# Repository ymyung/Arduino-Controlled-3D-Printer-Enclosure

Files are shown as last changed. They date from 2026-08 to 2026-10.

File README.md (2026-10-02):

# Arduino-Controlled 3D Printer Enclosure

This portfolio project combines an Arduino-based temperature-control prototype with a later SolidWorks electronics-packaging extension. It documents analog temperature sensing, PWM fan actuation, prototype testing, electrical integration, parametric enclosure design, assembly modelling, and engineering drawings while keeping the original group work separate from the independent CAD work.

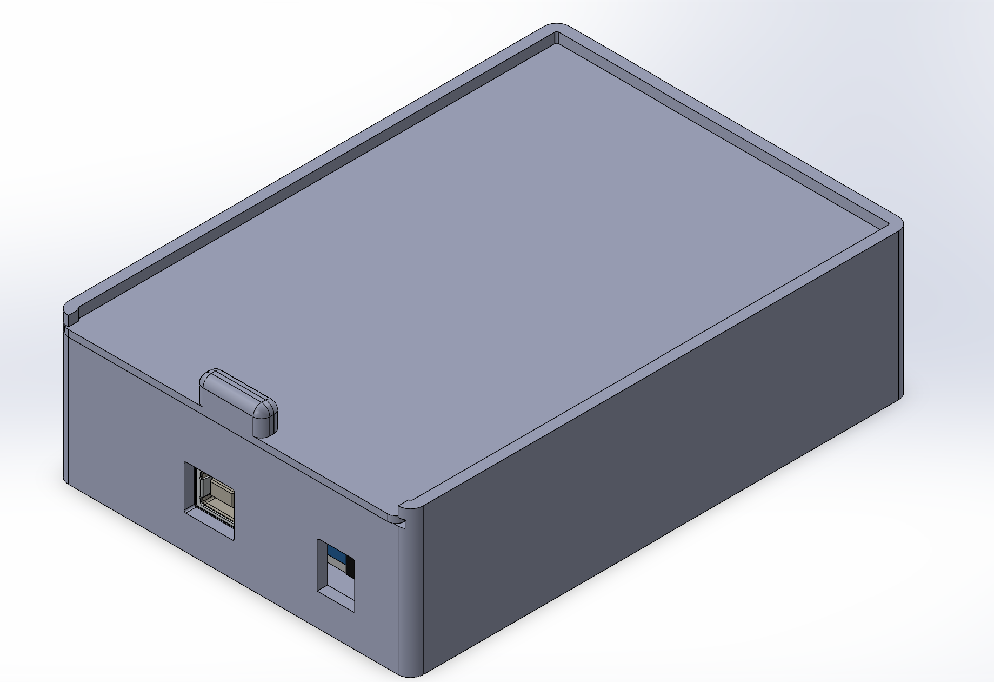
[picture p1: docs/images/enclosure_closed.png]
Closed SolidWorks assembly of the Arduino control enclosure


*Closed assembly showing the Arduino controller packaged within the electronics enclosure.*

## Project Overview

### Phase 1 - Thermal-Control Prototype

**Original group project | January-April 2025**

**My role: Electrical Lead**

The group project developed a temperature-regulation system for a 3D-printer enclosure. My work covered the Arduino control system, analog temperature-sensor integration, MOSFET-switched PWM fan control, live monitoring, electrical subsystem integration, system testing, troubleshooting, and wiring/system documentation.

The retained firmware and hardware documentation identify the sensor as an **LM35 analog temperature sensor**. It measures the main printer-enclosure temperature, and the cooling fans act on that main enclosure.

### Phase 2 - Mechanical Control Enclosure

**Independent mechanical design extension | 2026**

I later revisited the project independently to design a dedicated electronics/control enclosure in SolidWorks. This work was not part of the January-April 2025 group deliverable. It extends the project through mechanical packaging, Arduino placement, connector access, external cable routing, a guided sliding lid, assembly configurations, and a three-drawing documentation package.

## System Architecture

```mermaid
flowchart LR
    subgraph MAIN[Main printer enclosure]
        SENSOR[LM35 temperature sensor]
        FANS[DC cooling fans]
    end

    subgraph BOX[Electronics/control enclosure]
        MCU[Arduino Uno controller]
        LOGIC[Threshold and PWM logic]
        DRIVER[MOSFET fan driver]
    end

    SETPOINT[10 kOhm setpoint potentiometer] -->|A1| MCU
    SENSOR -->|External sensor connection / A0| MCU
    MCU --> LOGIC
    LOGIC -->|PWM D3| DRIVER
    DRIVER -->|External fan connection| FANS
    MCU -->|I2C| LCD[16 x 2 status display]
```

The mechanical control enclosure houses the Arduino/control hardware. The temperature sensor and cooling fans remain associated with the main printer enclosure, with their wiring routed through external enclosure connections.

## Mechanical Design

The independent SolidWorks work includes:

- a control-enclosure base with an approximately 120 mm x 85 mm x 35 mm overall envelope, approximately 2.5 mm walls, and R3 exterior corner treatment;
- Arduino mounting bosses/standoffs and packaging space for an Uno R3-style controller model;
- USB-B and power access plus routing for external sensor/fan wiring;
- rail/groove guide geometry for a removable sliding lid;
- an approximately 116 mm x 80.5 mm x 1.6 mm lid with a front pull feature and rear travel-limiting geometry;
- OPEN and CLOSED assembly configurations controlled by configuration-specific mates; and
- an exploded assembly representation for design communication.

The lid is screwless and is not documented as a snap-fit. The included Arduino model is used as a packaging reference; its original source and license are not established in the repository, so no authorship claim is made for that model.

See [Mechanical Design Notes](docs/mechanical-design.md) for the CAD structure, interfaces, and current validation boundaries.

## CAD Assembly

### Closed Configuration

Closed assembly

*Closed assembly showing the controller packaged within the electronics enclosure.*

### Open Configuration

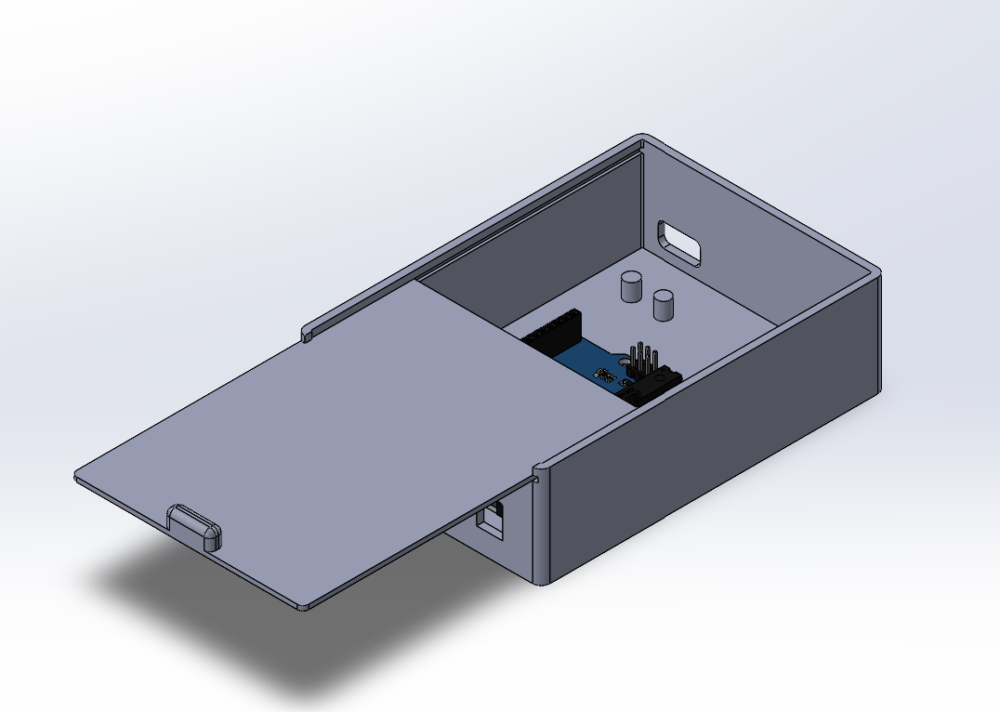
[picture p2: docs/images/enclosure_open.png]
Open assembly


*Open configuration showing the guided sliding-lid mechanism and internal component access.*

### Exploded Assembly

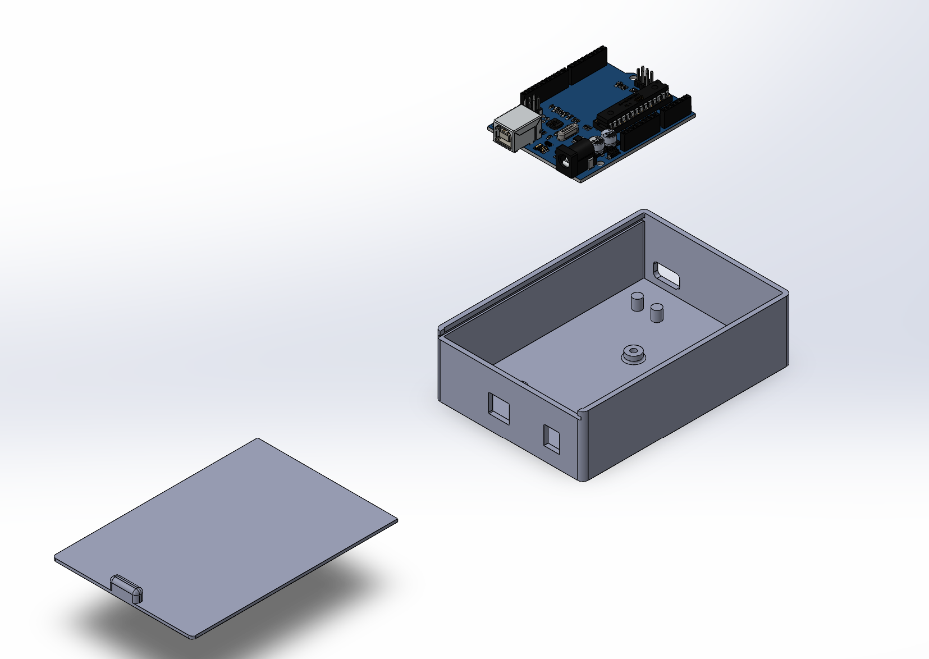
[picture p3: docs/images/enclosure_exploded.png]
Exploded assembly


*Exploded representation showing the relationship between the enclosure base, Arduino controller, and removable lid.*

## Component Design

### Control Enclosure Base

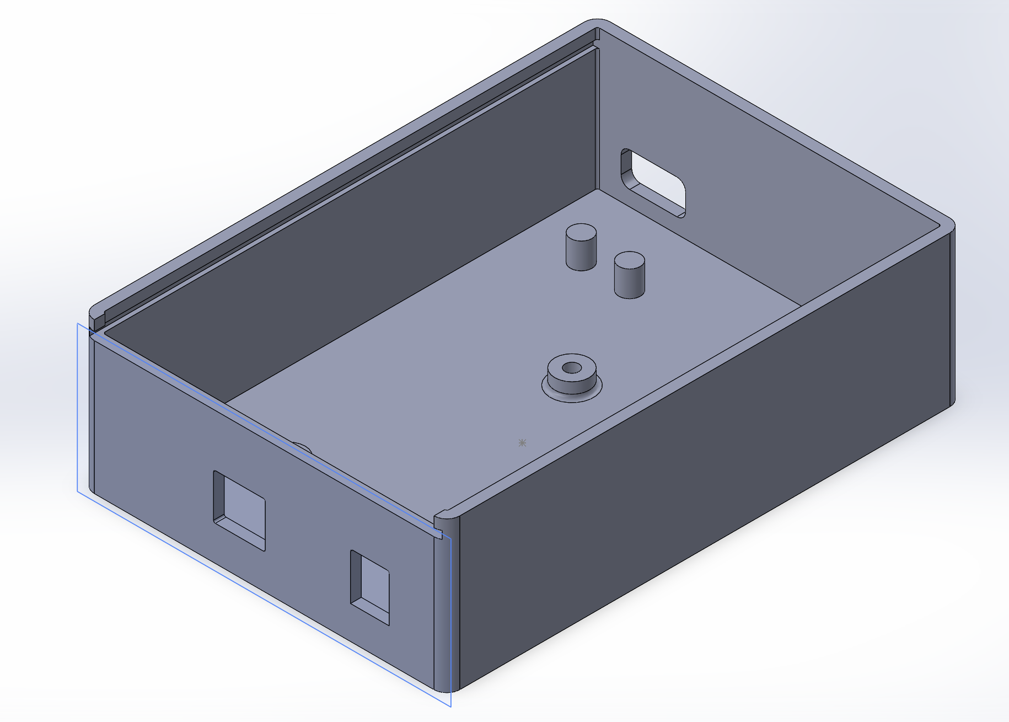
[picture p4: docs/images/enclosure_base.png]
Control enclosure base


*Base model incorporating controller mounting, connector access, external cable routing, and lid-guide geometry.*

### Sliding Lid

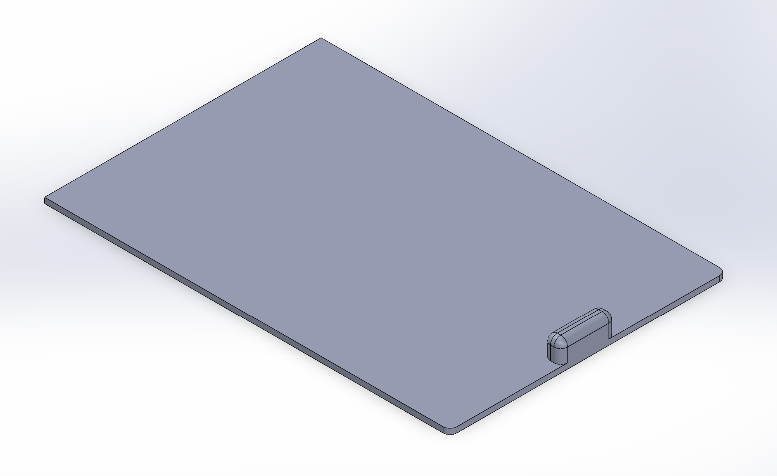
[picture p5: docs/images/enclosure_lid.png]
Sliding lid


*Removable lid designed around the enclosure rail/groove geometry, with a front pull feature.*

## Engineering Drawings

The native SolidWorks drawings are retained with the part and assembly files, with one-sheet PDF exports provided for browser-based review.

| Drawing | Description | PDF |
| --- | --- | --- |
| ACE-001 | Arduino Control Enclosure Base | [View Drawing](docs/drawings/ACE-001_Arduino_Control_Enclosure_Base.pdf) |
| ACE-002 | Arduino Control Enclosure Sliding Lid | [View Drawing](docs/drawings/ACE-002_Arduino_Control_Enclosure_Sliding_Lid.pdf) |
| ACE-003 | Arduino Control Enclosure Assembly | [View Drawing](docs/drawings/ACE-003_Arduino_Control_Enclosure_Assembly.pdf) |

ACE-001 includes dimensioned base views and section A-A; ACE-002 includes dimensioned lid and isometric views; ACE-003 includes closed, open, and exploded assembly views with a three-item BOM and item balloons. Exact source and output filenames are listed in [`docs/drawings/README.md`](docs/drawings/README.md). No claim is made for GD&T, production tolerances, material specifications, surface finish, or production readiness.

## Electrical & Control System

The retained Arduino firmware implements a threshold-based variable-speed controller:

- The LM35 signal on A0 and setpoint potentiometer on A1 are each averaged over 20 ADC samples.
- The potentiometer maps to a 25-40 °C threshold using floating-point range mapping.
- At or below the threshold, target fan PWM is zero.
- Above the threshold, the target command increases over the next 10 °C and is constrained to 80-255.
- A floating-point accumulator applies a 0.1 smoothing factor before the command is rounded for `analogWrite()`.
- PWM pin D3 drives the fan load through an n-channel MOSFET.
- A 16 x 2 I2C LCD and 9600-baud serial output report temperature, setpoint, and commanded fan percentage.

This is not PID control and it does not measure fan RPM. See the [firmware](firmware/fan_controller.ino) and [control-logic notes](docs/control_logic.md) for the implementation.

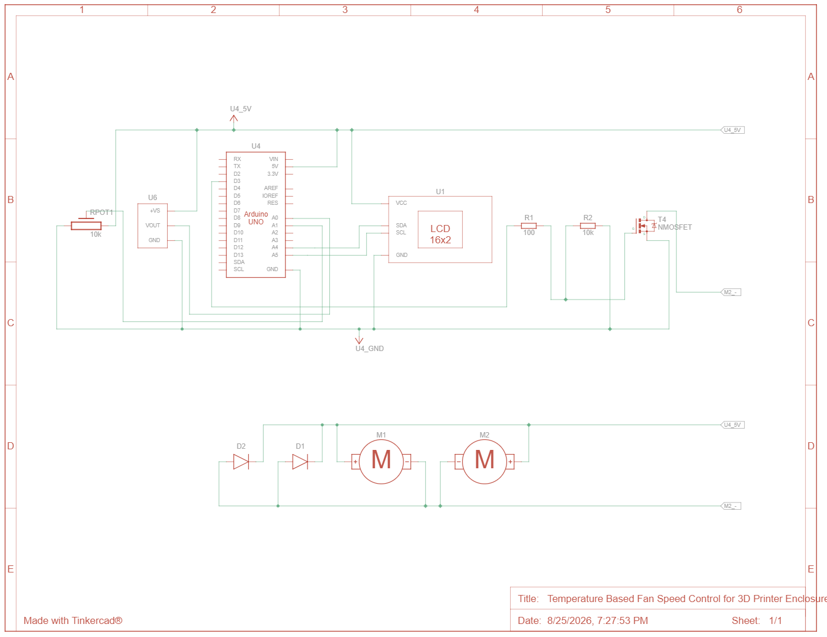
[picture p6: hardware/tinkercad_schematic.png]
Tinkercad schematic of the temperature-based fan-control circuit


*Retained circuit schematic. The TMP36 symbol is a visual stand-in for the LM35 documented in the physical prototype and firmware.*

## Testing and Retained Evidence

The original electrical prototype was operated while readings and system behaviour were monitored for integration, testing, and troubleshooting. Retained evidence includes the source code, Tinkercad schematic, component documentation, a [hosted prototype photo](https://github.com/user-attachments/assets/a48dc317-c163-46c9-83ad-6458d7b99006), and a [working-system demonstration](https://drive.google.com/file/d/1cJ_dpvMLTJp6Dsobzo3_qu-2Yc8-_ou2/view?usp=sharing).

This evidence is qualitative. The repository does not contain a retained calibration dataset, fan-RPM measurements, a controlled thermal-response dataset, or repeatability results; no numerical accuracy or closed-loop performance is claimed.

## Engineering Skills Demonstrated

**Mechanical:** SolidWorks, parametric part modelling, assembly modelling, mechanical packaging, engineering drawings, exploded assemblies, and component integration.

**Electrical / embedded:** Arduino programming, analog temperature sensing, ADC sampling, PWM control, MOSFET fan switching, LCD/serial monitoring, and hardware/software integration.

**Engineering practice:** electromechanical integration, prototype testing, troubleshooting, technical documentation, and iterative design.

## Repository Structure

```text
arduino-3d-printer-enclosure/
|-- README.md
|-- firmware/
|   `-- fan_controller.ino
|-- hardware/
|   |-- BOM.md
|   |-- README.md
|   |-- tinkercad_schematic.png
|   |-- tinkercad_component_list.png
|   `-- part files/
|       |-- Control_Enclosure_Base.SLDPRT
|       |-- Enclosure_lid.SLDPRT
|       |-- enclosure_assembly.SLDASM
|       |-- arduino uno.SLDPRT
|       `-- ACE-001/002/003 native SolidWorks drawings
|-- docs/
|   |-- control_logic.md
|   |-- design_decisions.md
|   |-- testing_and_limitations.md
|   |-- mechanical-design.md
|   |-- drawings/
|   |   `-- README.md
|   `-- images/
|       `-- five SolidWorks design views
`-- media/
    `-- README.md
```

Native CAD files remain in their original directory and retain their existing filenames to avoid disrupting assembly or drawing references.

## Design Status / Future Work

The repository contains the original controller firmware and qualitative prototype evidence, plus native CAD parts, an assembly, screenshots, three native drawings, and verified PDF exports for the independent mechanical extension. The control enclosure has not been documented here as physically fabricated or fit-validated.

Remaining engineering work includes:

- fabricating the control enclosure;
- verifying Arduino, connector, and cable fit on physical parts;
- checking sliding-lid operation and clearances after fabrication; and
- iterating the CAD and drawings from measured build results.

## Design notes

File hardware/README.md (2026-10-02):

# Hardware Documentation

This folder contains the retained electrical documentation and the native SolidWorks package for the 3D-printer enclosure controller.

- [`BOM.md`](BOM.md) - electrical bill of materials
- [`tinkercad_schematic.png`](tinkercad_schematic.png) - reconstructed Tinkercad circuit schematic
- [`tinkercad_component_list.png`](tinkercad_component_list.png) - component-list screenshot
- `part files/` - native enclosure parts, assembly, drawings, Arduino packaging model, and source screenshots

## Native CAD Safety

The files in `part files/` intentionally retain their current names and locations because SolidWorks assemblies and drawings can contain external references. Do not rename, move, or replace the native `.SLDPRT`, `.SLDASM`, or `.SLDDRW` files solely for repository organization.

The included `arduino uno.SLDPRT` is used as a packaging reference. Its original source and license are not documented here, so this project does not claim authorship of that model.

## Sensor Note

The physical prototype used an **LM35 analog temperature sensor**. Tinkercad did not provide an LM35 component, so the schematic uses a **TMP36 symbol only as a visual substitute**. The firmware is written for the LM35 transfer characteristic.

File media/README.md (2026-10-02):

# Demo Media

Qualitative evidence from the original electrical-control prototype is hosted externally:

- [Physical-prototype photograph](https://github.com/user-attachments/assets/a48dc317-c163-46c9-83ad-6458d7b99006)
- [Working-system demonstration](https://drive.google.com/file/d/1cJ_dpvMLTJp6Dsobzo3_qu-2Yc8-_ou2/view?usp=sharing)

These artifacts support the documented integration/testing history but do not provide a quantitative calibration, fan-RPM, response-time, or repeatability dataset. The later SolidWorks control enclosure is a separate 2026 design extension and is not shown as physically fabricated by this media.

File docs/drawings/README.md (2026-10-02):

# Engineering Drawing PDFs

This directory contains one-sheet PDF exports of the native SolidWorks engineering drawings retained in `hardware/part files/`. The native files remain the governing CAD documents and must not be renamed or moved because their references may depend on the existing paths.

The PDFs were opened with the Windows PDF renderer and visually checked for readable sheet output and the contents summarized below.

| Native drawing | PDF export | Verified sheet content |
| --- | --- | --- |
| `ACE-001_Arduino_Control_Enclosure_Base.SLDDRW` | [ACE-001 Base](ACE-001_Arduino_Control_Enclosure_Base.pdf) | Dimensioned base views, section A-A, and isometric view |
| `ACE-002_Sliding_Lid.SLDDRW` | [ACE-002 Sliding Lid](ACE-002_Arduino_Control_Enclosure_Sliding_Lid.pdf) | Dimensioned lid views and isometric view |
| `ACE-003_Arduino_Control_Enclosure_Assembly.SLDDRW` | [ACE-003 Assembly](ACE-003_Arduino_Control_Enclosure_Assembly.pdf) | Closed, open, and exploded assembly views; three-item BOM; item balloons |

When a native drawing changes, regenerate and revalidate its PDF without saving documentation-only changes back into the SolidWorks file.

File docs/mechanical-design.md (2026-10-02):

# Mechanical Design Notes

## Scope and Project History

The electronics/control enclosure is an independent 2026 extension of the original January-April 2025 group thermal-control project. It packages the Arduino/control hardware and provides the required external connections; it does not relocate the temperature sensor or cooling fans from the main printer enclosure.

The values below are the approximate dimensions recorded for this design. The native SolidWorks parts and drawings remain the governing design files.

## Enclosure Base

The control-enclosure base is approximately 120 mm x 85 mm x 35 mm overall, with approximately 2.5 mm walls and an R3 exterior corner treatment. Its functional features include:

- mounting bosses/standoffs for an Arduino Uno R3-style controller;
- access for the board's USB-B and power connections;
- an opening for external sensor/fan cable routing; and
- rail/groove geometry that guides the removable lid.

The base is represented by `hardware/part files/Control_Enclosure_Base.SLDPRT` and drawing ACE-001.

## Sliding Lid

The lid is approximately 116 mm x 80.5 mm x 1.6 mm. It slides within the enclosure guide geometry and includes a front pull/finger feature. Rear geometry limits lid travel/closure. The design does not use screws, and no snap-fit behaviour is claimed.

The lid is represented by `hardware/part files/Enclosure_lid.SLDPRT` and drawing ACE-002.

## Assembly Model

The assembly combines the enclosure base, sliding lid, and an Arduino Uno R3-style packaging model. It includes OPEN and CLOSED configurations with configuration-specific mates controlling lid position, plus an exploded representation.

The Arduino model supports placement and access studies. Its original source and license are not documented in this repository, so the project does not claim authorship of that model.

The assembly is represented by `hardware/part files/enclosure_assembly.SLDASM` and drawing ACE-003.

## Electromechanical Interfaces

The packaging work addresses the interfaces visible in the retained CAD:

- controller support and placement inside the base;
- external access to USB-B and power connections;
- routing for wiring to the printer-enclosure temperature sensor and fan load; and
- access to the electronics through the removable lid.

The temperature sensor and cooling fans remain part of the main printer-enclosure system rather than components inside this control box.

## Native CAD and Drawing Package

The native directory intentionally retains the original filenames because SolidWorks parts, assemblies, and drawings can depend on path and filename references. The directory contains:

| File | Purpose |
| --- | --- |
| `Control_Enclosure_Base.SLDPRT` | Enclosure base part |
| `Enclosure_lid.SLDPRT` | Sliding-lid part |
| `enclosure_assembly.SLDASM` | Control-enclosure assembly |
| `arduino uno.SLDPRT` | Arduino packaging model; authorship/source not established here |
| `ACE-001_Arduino_Control_Enclosure_Base.SLDDRW` | Base drawing |
| `ACE-002_Sliding_Lid.SLDDRW` | Lid drawing |
| `ACE-003_Arduino_Control_Enclosure_Assembly.SLDDRW` | Assembly drawing |

## Current Validation Boundary

The repository does not contain evidence that the mechanical enclosure was fabricated or physically fit-checked. It also does not establish production tolerances, material specifications, surface finish, tolerance-stack analysis, interference validation, DFM validation, FEA, CFD, thermal simulation, or airflow improvement. Those items are outside the documented scope until supported by future build and validation work.

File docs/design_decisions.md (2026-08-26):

# Design Decisions

This document records the main electrical and firmware choices visible in the retained project artifacts.

## 1. LM35 temperature sensing

The physical prototype used an **LM35** analog temperature sensor. The firmware assumes the LM35 relationship of approximately 10 mV/°C and converts the measured ADC voltage using:

```cpp
float tempVoltage = tempAvg * (5.0 / 1023.0);
float temperatureC = tempVoltage * 100.0;
```

The Tinkercad schematic uses a TMP36 symbol because an LM35 component was not available in that environment. The TMP36 is a schematic stand-in only and should not be used to interpret the firmware conversion.

## 2. User-adjustable temperature threshold

A **10 kΩ potentiometer** provides an analog input that is mapped to a 25–40 °C setpoint. This makes the cooling threshold adjustable without recompiling the firmware.

## 3. MOSFET interface for the fans

The Arduino generates the fan command as a PWM signal on pin D3. An **n-channel MOSFET** is used as the switching element between the Arduino control signal and the fan load.

The retained schematic also includes a 100 Ω resistor in the MOSFET gate path and a 10 kΩ resistor at the gate control node.

## 4. Analog input averaging

Both the temperature and potentiometer signals are averaged over **20 ADC readings**. The intent is to reduce short-term fluctuations before the values are used by the controller.

## 5. Threshold-based variable-speed control

The system does not use PID control. The logic is:

- at or below the selected threshold: target PWM = 0;
- above the threshold: target PWM increases with measured temperature;
- active target PWM is constrained to 80–255.

This gives the system variable fan command above the threshold while avoiding very low active PWM commands.

## 6. Smoothed PWM command

Rather than switching immediately to each newly calculated target, the firmware updates the output using:

```text
smoothedPWM = smoothedPWM + 0.1 × (targetPWM - smoothedPWM)
```

This makes commanded fan-speed changes more gradual.

## 7. Two forms of operating feedback

The project uses both:

- a **16×2 I²C LCD** for local feedback; and
- **9600-baud serial output** for diagnostic monitoring during development and testing.

The LCD presents measured temperature, selected threshold, and commanded fan percentage.

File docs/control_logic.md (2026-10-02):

# Control Logic

## Overview

The enclosure uses a threshold-based variable-speed cooling strategy.

The controller has two primary inputs:

1. Enclosure temperature measured using an LM35 sensor
2. Desired temperature selected using a potentiometer

The primary output is a PWM command sent from the Arduino to the MOSFET controlling the two fans.

The controller does not measure actual fan RPM.

## Control Sequence

Each control cycle follows this sequence:

```text
Read LM35
    |
    v
Average ADC samples
    |
    v
Convert ADC value to voltage
    |
    v
Convert voltage to temperature
    |
    +----------------------+
                           |
Read potentiometer         |
    |                      |
    v                      |
Average ADC samples        |
    |                      |
    v                      |
Map reading to 25-40 C ----+
                           |
                           v
               Compare temperature
                   with setpoint
                           |
             +-------------+-------------+
             |                           |
      Temp <= Setpoint            Temp > Setpoint
             |                           |
             v                           v
       Target PWM = 0          Calculate PWM 80-255
             |                           |
             +-------------+-------------+
                           |
                           v
                     Smooth output
                           |
                           v
                    MOSFET PWM signal
                           |
                           v
                       Two fans
```

## Input Averaging

Both analog inputs are sampled 20 times.

The samples are averaged before being used by the controller.

This reduces small ADC fluctuations without requiring additional filtering hardware.

The firmware uses:

```cpp
const int NUM_SAMPLES = 20;
```

with approximately 2 ms between individual samples.

## LM35 Temperature Conversion

The Arduino Uno ADC produces values from:

```text
0 to 1023
```

using an approximately 5 V reference.

Voltage is calculated as:

```text
voltage = ADC × (5.0 / 1023)
```

The physical prototype used an LM35 sensor.

The LM35 produces approximately:

```text
10 mV / °C
```

Therefore:

```text
temperature (°C) = voltage / 0.010
```

The Tinkercad schematic uses a TMP36 symbol only because the original simulation environment did not provide the LM35 component.

The firmware uses the LM35 conversion relationship.

## Setpoint Calculation

The potentiometer is connected to a second analog input.

Its averaged ADC reading is mapped to:

```text
25 °C to 40 °C
```

The controller uses floating-point mapping rather than Arduino's standard integer `map()` function so fractional averaged ADC values and temperature values can be preserved.

## Cooling Threshold

When:

```text
measured temperature <= desired temperature
```

the target fan PWM is:

```text
0
```

When:

```text
measured temperature > desired temperature
```

active cooling begins.

## Variable Fan Command

Once active cooling is required, the target PWM command begins at:

```text
80 / 255
```

and increases as measured temperature rises.

The controller reaches maximum commanded PWM when the measured temperature is approximately:

```text
10 °C above the selected setpoint
```

Therefore the operating relationship is approximately:

```text
T <= Tset
PWM = 0
```

```text
Tset < T < Tset + 10 °C
PWM = proportional value between 80 and 255
```

```text
T >= Tset + 10 °C
PWM = 255
```

The value 80 was used as the minimum active PWM command because very small PWM duty cycles may not reliably start a DC fan.

No fan-start threshold was experimentally characterized and retained, so this value should not be interpreted as a measured minimum operating requirement.

## PWM Smoothing

The controller applies exponential smoothing to PWM changes:

```text
smoothedPWM =
smoothedPWM
+ (targetPWM - smoothedPWM) × 0.10
```

A floating-point accumulator is used to prevent fractional updates from being lost through integer truncation.

When cooling first becomes active, the **target** command is at least 80/255. Because the actual output is smoothed toward that target, the first PWM values sent by `analogWrite()` can be below 80.

When cooling is no longer required, the command decreases toward zero.

When the floating-point accumulator falls below 1.0 with a zero target, the firmware sets it to zero.

The purpose of smoothing is to reduce abrupt changes in commanded fan output.

## MOSFET Output Stage

Arduino PWM pin 3 provides the control signal to the N-channel MOSFET circuit.

The Arduino does not directly supply the fan operating current.

Instead:

```text
Arduino PWM
    |
    v
MOSFET gate
    |
    v
MOSFET switches fan current
    |
    v
Two DC fans
```

## Fan Percentage

The displayed fan percentage is calculated from the PWM command:

```text
fan percentage =
PWM / 255 × 100
```

For example:

```text
PWM = 128
```

corresponds to approximately:

```text
50% commanded PWM
```

This does not mean the fan is rotating at 50% of its maximum RPM.

Actual fan speed was not measured.

## Controller Classification

The system should be described as:

> Threshold-based variable-speed fan control with PWM output smoothing.

It should not be described as:

- PID control
- Closed-loop fan-speed control
- Closed-loop RPM control

The temperature measurement influences fan command, but there is no feedback measurement of actual fan speed.

## Update Rate

The main control logic runs approximately every:

```text
500 ms
```

Additional time is required to acquire the averaged analog samples.

This update rate was sufficient for the relatively slow thermal behavior of the enclosure prototype.

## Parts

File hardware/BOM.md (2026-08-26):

# Bill of Materials

The following list is based on the retained Tinkercad component list and the known physical build.

| Component | Quantity | Notes |
|---|---:|---|
| Arduino Uno R3 | 1 | Main controller |
| LM35 temperature sensor | 1 | Used in the physical prototype |
| 10 kΩ potentiometer | 1 | User-adjustable temperature setpoint |
| 16×2 I²C LCD (PCF8574-based, address 0x27 in firmware) | 1 | Displays measured temperature, setpoint, and commanded fan output |
| DC fan / DC motor | 2 | Cooling loads controlled together |
| n-channel MOSFET | 1 | Switches the fan load from the Arduino PWM signal |
| 100 Ω resistor | 1 | Shown in the MOSFET gate path in the schematic |
| 10 kΩ resistor | 1 | Shown as the MOSFET gate pull-down in the schematic |
| Diode | 2 | Included with the two motor branches in the retained schematic |
| Small breadboard | 1 | Prototype wiring |

## Tinkercad sensor substitution

The physical prototype used an **LM35** temperature sensor. Tinkercad did not provide an LM35 component, so the retained Tinkercad schematic uses a **TMP36 symbol as a visual stand-in**. The firmware is written for the LM35 transfer characteristic, not the TMP36 transfer characteristic.

See [`tinkercad_component_list.png`](tinkercad_component_list.png) for the original component-list screenshot.

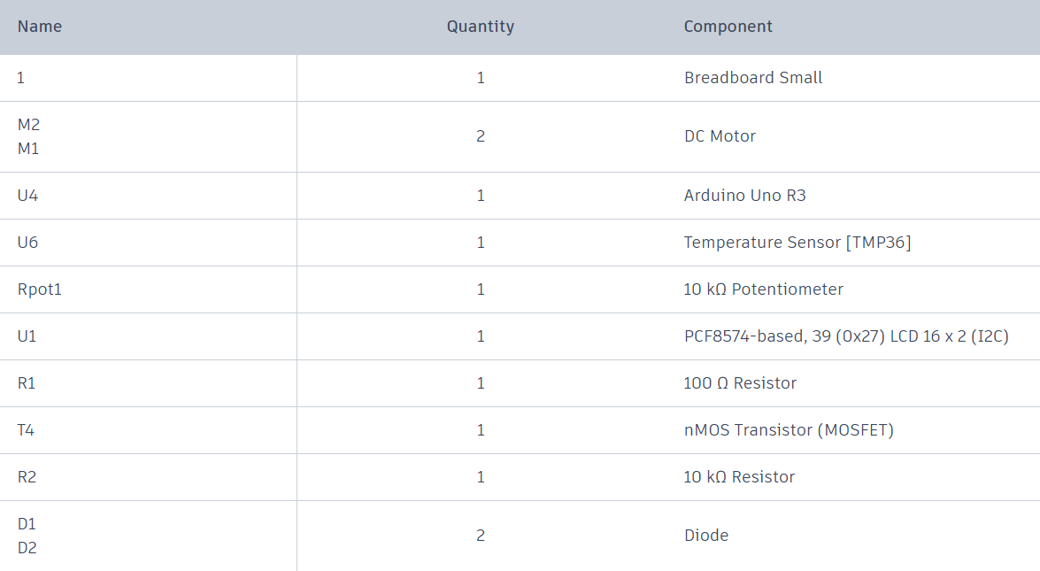
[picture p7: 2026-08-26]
hardware/tinkercad_component_list.png

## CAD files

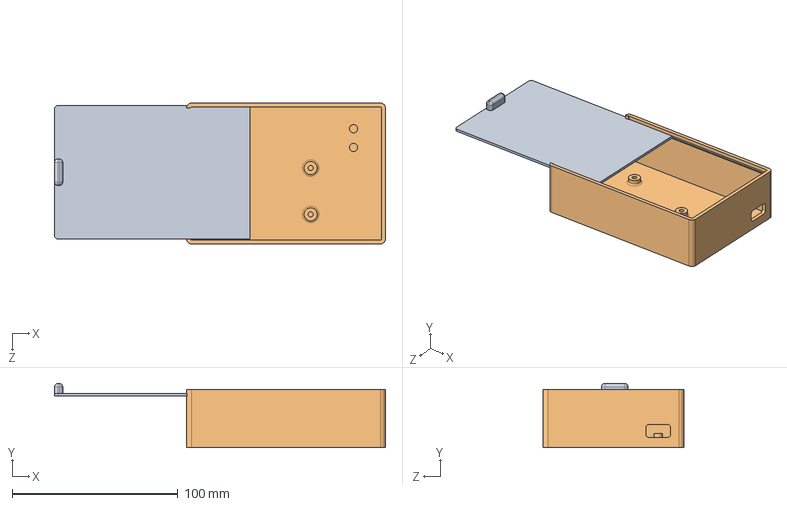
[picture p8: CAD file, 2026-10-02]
hardware/part files/enclosure_assembly.SLDASM
199.6 x 38.6 x 85.0 mm
Control_Enclosure_Base
Enclosure_lid

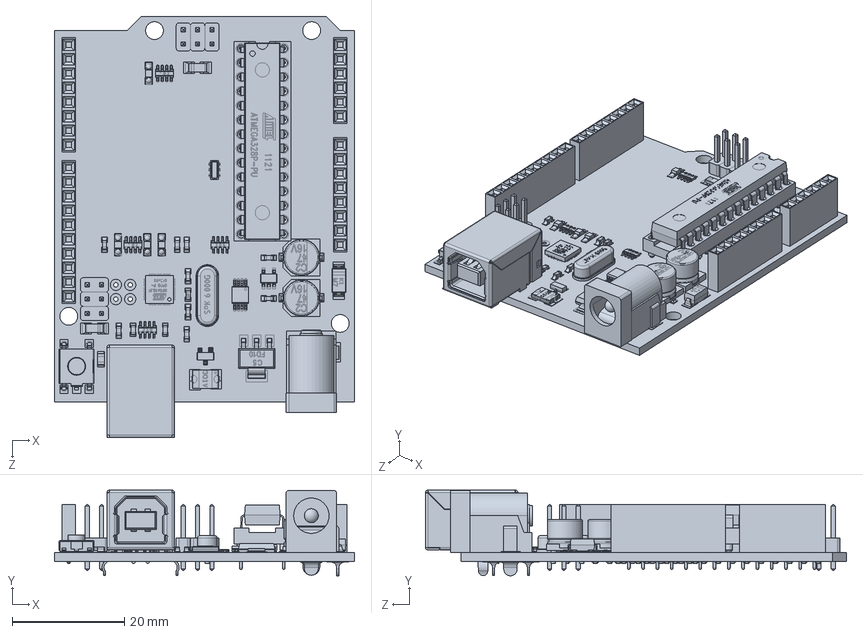
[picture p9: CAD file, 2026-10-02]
hardware/part files/arduino uno.SLDPRT
53.3 x 15.2 x 74.9 mm

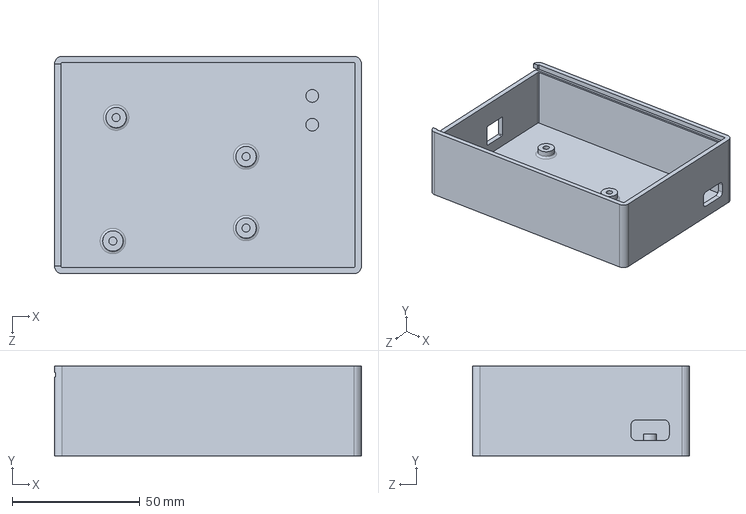
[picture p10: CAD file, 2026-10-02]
hardware/part files/Control_Enclosure_Base.SLDPRT
120.0 x 35.0 x 85.0 mm

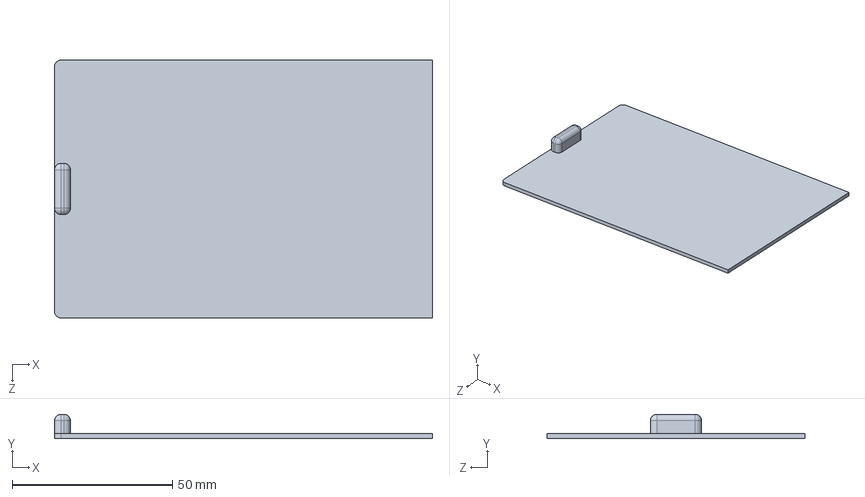
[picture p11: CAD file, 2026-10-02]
hardware/part files/Enclosure_lid.SLDPRT
118.0 x 7.60 x 80.5 mm

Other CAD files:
hardware/part files/ACE-001_Arduino_Control_Enclosure_Base.SLDDRW
hardware/part files/ACE-002_Sliding_Lid.SLDDRW
hardware/part files/ACE-003_Arduino_Control_Enclosure_Assembly.SLDDRW

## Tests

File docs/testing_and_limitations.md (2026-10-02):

# Testing and Limitations

## Prototype Status

The original group project's Arduino-based thermal-control prototype was constructed and operated. This statement refers to the electrical/control prototype for the main printer enclosure, not the later 2026 electronics control-box CAD.

Available retained evidence includes:

- A [hosted physical-prototype photograph](https://github.com/user-attachments/assets/a48dc317-c163-46c9-83ad-6458d7b99006)
- A [hosted working-system demonstration](https://drive.google.com/file/d/1cJ_dpvMLTJp6Dsobzo3_qu-2Yc8-_ou2/view?usp=sharing)
- Arduino firmware
- A reconstructed Tinkercad circuit diagram
- A component list
- Project documentation

The retained project material supports the existence and operation of the prototype, but it does not contain a complete quantitative validation dataset.

The independent 2026 mechanical extension is supported by native SolidWorks parts, an assembly, five CAD screenshots, and three native SolidWorks drawings. These artifacts document a design, not physical fabrication or fit validation of the control enclosure.

## Functional Testing

During development, the system was checked for basic functional behavior.

The intended operating sequence was:

1. Read temperature from the LM35 sensor
2. Read the desired temperature from the potentiometer
3. Display system information on the LCD
4. Keep the fans off when cooling was not required
5. Activate the fans when measured temperature exceeded the selected temperature
6. Increase commanded fan PWM as temperature increased
7. Observe measurements and controller outputs through the serial connection

The available project evidence supports functional prototype operation.

However, detailed quantitative test records from the original development period were not retained.

## Serial Diagnostics

The firmware outputs:

- Measured temperature
- Selected temperature
- Target PWM
- Actual smoothed PWM command
- Commanded fan percentage

This provides a practical way to inspect controller behavior during testing and troubleshooting.

Example:

```text
Temperature: 31.2 C | Setpoint: 29.5 C | Target PWM: 109 | Output PWM: 96 | Fan command: 38%
```

## Temperature Measurement Limitations

The physical prototype used an LM35 sensor.

The firmware uses the nominal LM35 relationship of approximately:

```text
10 mV / °C
```

No retained calibration dataset compares the LM35 measurements against a traceable reference thermometer.

Therefore the repository does not claim a measured temperature accuracy.

ADC measurements also depend on the Arduino supply/reference voltage, which was treated as approximately 5 V.

## Fan-Control Limitations

The fans are controlled using PWM through a MOSFET.

The system does not contain fan-speed feedback.

Therefore:

```text
PWM percentage != measured fan RPM percentage
```

The displayed fan percentage represents only the electrical PWM command generated by the Arduino.

No retained measurements exist for:

- Fan RPM
- Airflow
- Fan start threshold
- Fan stall threshold
- Current consumption across PWM levels

The minimum active PWM value used by the firmware should therefore be treated as a design choice rather than an experimentally validated specification.

## Controller Limitations

The controller is not PID control.

It uses:

- A user-selected temperature threshold
- Proportional PWM mapping above that threshold
- PWM output smoothing

No formal controller tuning procedure was performed.

No quantitative measurements were retained for:

- Overshoot
- Settling time
- Steady-state temperature error
- Disturbance rejection
- Thermal time constant

## Thermal-System Limitations

No retained controlled experiment compares:

- Enclosure temperature with fans disabled
- Enclosure temperature with fans enabled
- Different fan commands
- Different external ambient conditions
- Different printer operating loads

Because of this, the project should not claim a specific reduction in enclosure temperature or cooling-performance percentage.

## Hardware Limitations

The prototype was built using breadboard-level electronics.

It was not designed as production hardware.

Limitations include:

- No custom PCB
- No formal electrical safety certification
- No retained electromagnetic compatibility testing
- No retained long-duration reliability testing
- No fan tachometer feedback
- No automatic fan-stall detection
- No redundant temperature sensor
- No formal sensor-failure handling
- The 2026 CAD control enclosure is not documented as fabricated or physically fit-checked

## Tinkercad Schematic Limitation

The physical prototype used an LM35 temperature sensor.

The original Tinkercad environment did not provide an LM35 component, so the diagram uses a TMP36 symbol as a visual substitute.

This image documents the circuit architecture rather than providing an exact representation of the sensor component used in the physical build.

The Arduino firmware uses the LM35 conversion relationship.

## Firmware Improvements

The repository version of the firmware was cleaned up after the original prototype project to improve readability and technical correctness.

The cleaned version:

- Uses floating-point mapping for temperature and averaged ADC values
- Retains PWM smoothing using a floating-point accumulator
- Prevents stale characters on the LCD
- Separates sensing, control, display, and diagnostic logic into functions
- Clearly distinguishes commanded PWM from measured fan speed

These changes preserve the original system architecture and intended control behavior.

## What Is Supported by the Project Evidence

The project can reasonably demonstrate experience with:

- Arduino firmware
- Analog sensor acquisition
- LM35 temperature sensing
- Potentiometer input
- PWM output
- MOSFET-based load switching
- DC fan control
- I²C LCD communication
- Basic signal averaging
- Hardware/software integration
- Electrical troubleshooting
- Serial diagnostics
- Technical documentation

## Claims That Should Not Be Made

Without additional testing, the project should not be described as having demonstrated:

- A specific temperature-control accuracy
- A specific cooling-performance improvement
- Calibrated temperature measurement
- Measured fan RPM control
- PID control
- Experimentally optimized PWM thresholds
- Validated long-term reliability
- Physical fabrication or fit validation of the 2026 control enclosure
- Production tolerances, material specifications, surface finish, or production readiness for the CAD enclosure

## Future Validation

If the physical system were tested again, a useful validation experiment would record:

```text
time
measured temperature
temperature setpoint
target PWM
output PWM
ambient temperature
```

A temperature-versus-time plot could then be used to evaluate:

- Response time
- Cooling behavior
- Steady-state behavior
- Effect of different setpoints
- Effect of different fan commands

Fan tachometer feedback could also be added in a future design to compare commanded PWM with actual rotational speed.

For the mechanical extension, future validation should include enclosure fabrication, controller and connector fit checks, cable-routing checks, sliding-lid operation, and drawing/CAD revisions based on measured results.

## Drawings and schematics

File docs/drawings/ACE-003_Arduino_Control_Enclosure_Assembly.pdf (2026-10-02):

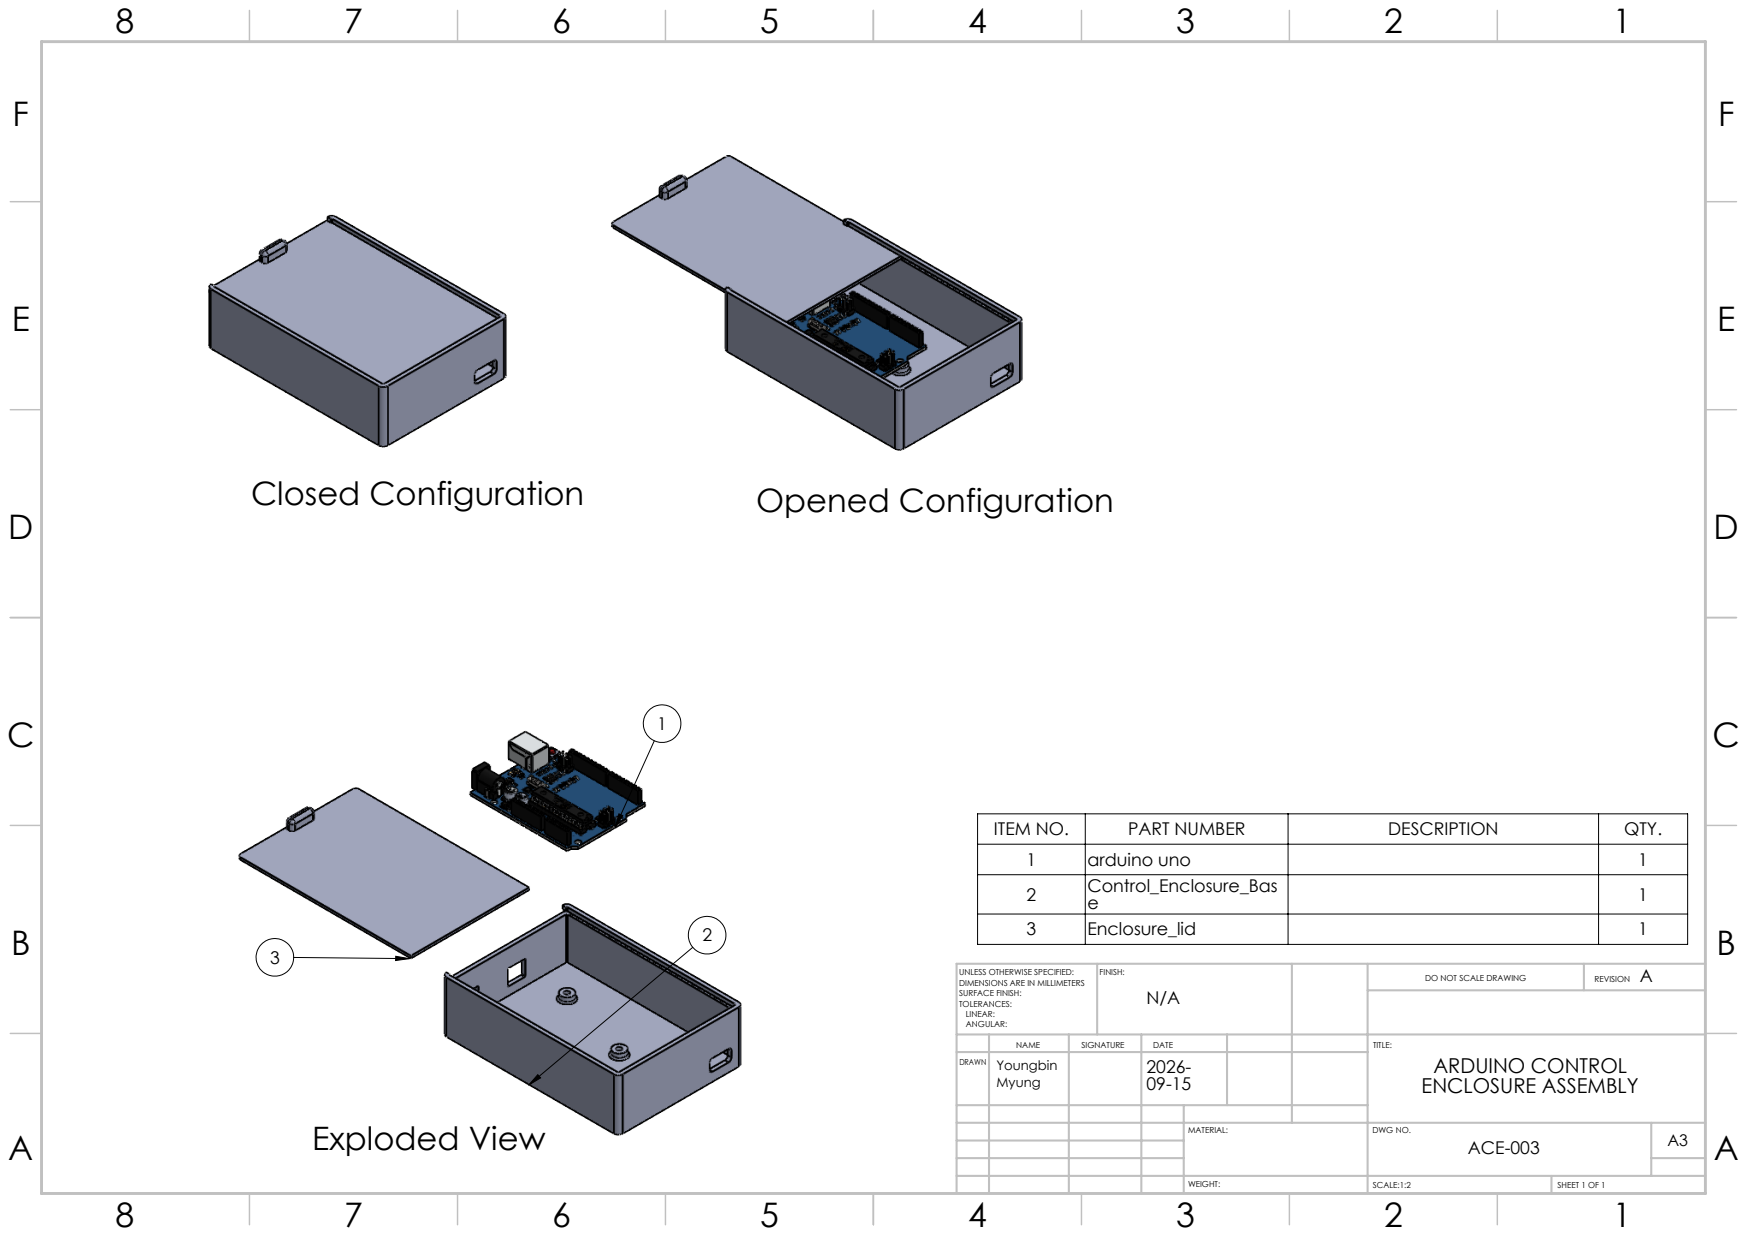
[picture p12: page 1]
Closed Configuration; Opened Configuration; Exploded View; DO NOT SCALE DRAWING; REVISION; DWG NO.; SCALE:1:2; SHEET 1 OF 1

ITEM NO. | PART NUMBER | DESCRIPTION | QTY.
1 | arduino uno | | 1
2 | Control_Enclosure_Bas e | | 1
3 | Enclosure_lid | | 1

UNLESS OTHERWISE SPECIFIED:
DIMENSIONS ARE IN MILLIMETERS
SURFACE FINISH:
TOLERANCES:
LINEAR:
ANGULAR:

NAME | SIGNATURE | DATE | TITLE: ARDUINO CONTROL ENCLOSURE ASSEMBLY

DRAWN | Youngbin Myung | | 2026-09-15

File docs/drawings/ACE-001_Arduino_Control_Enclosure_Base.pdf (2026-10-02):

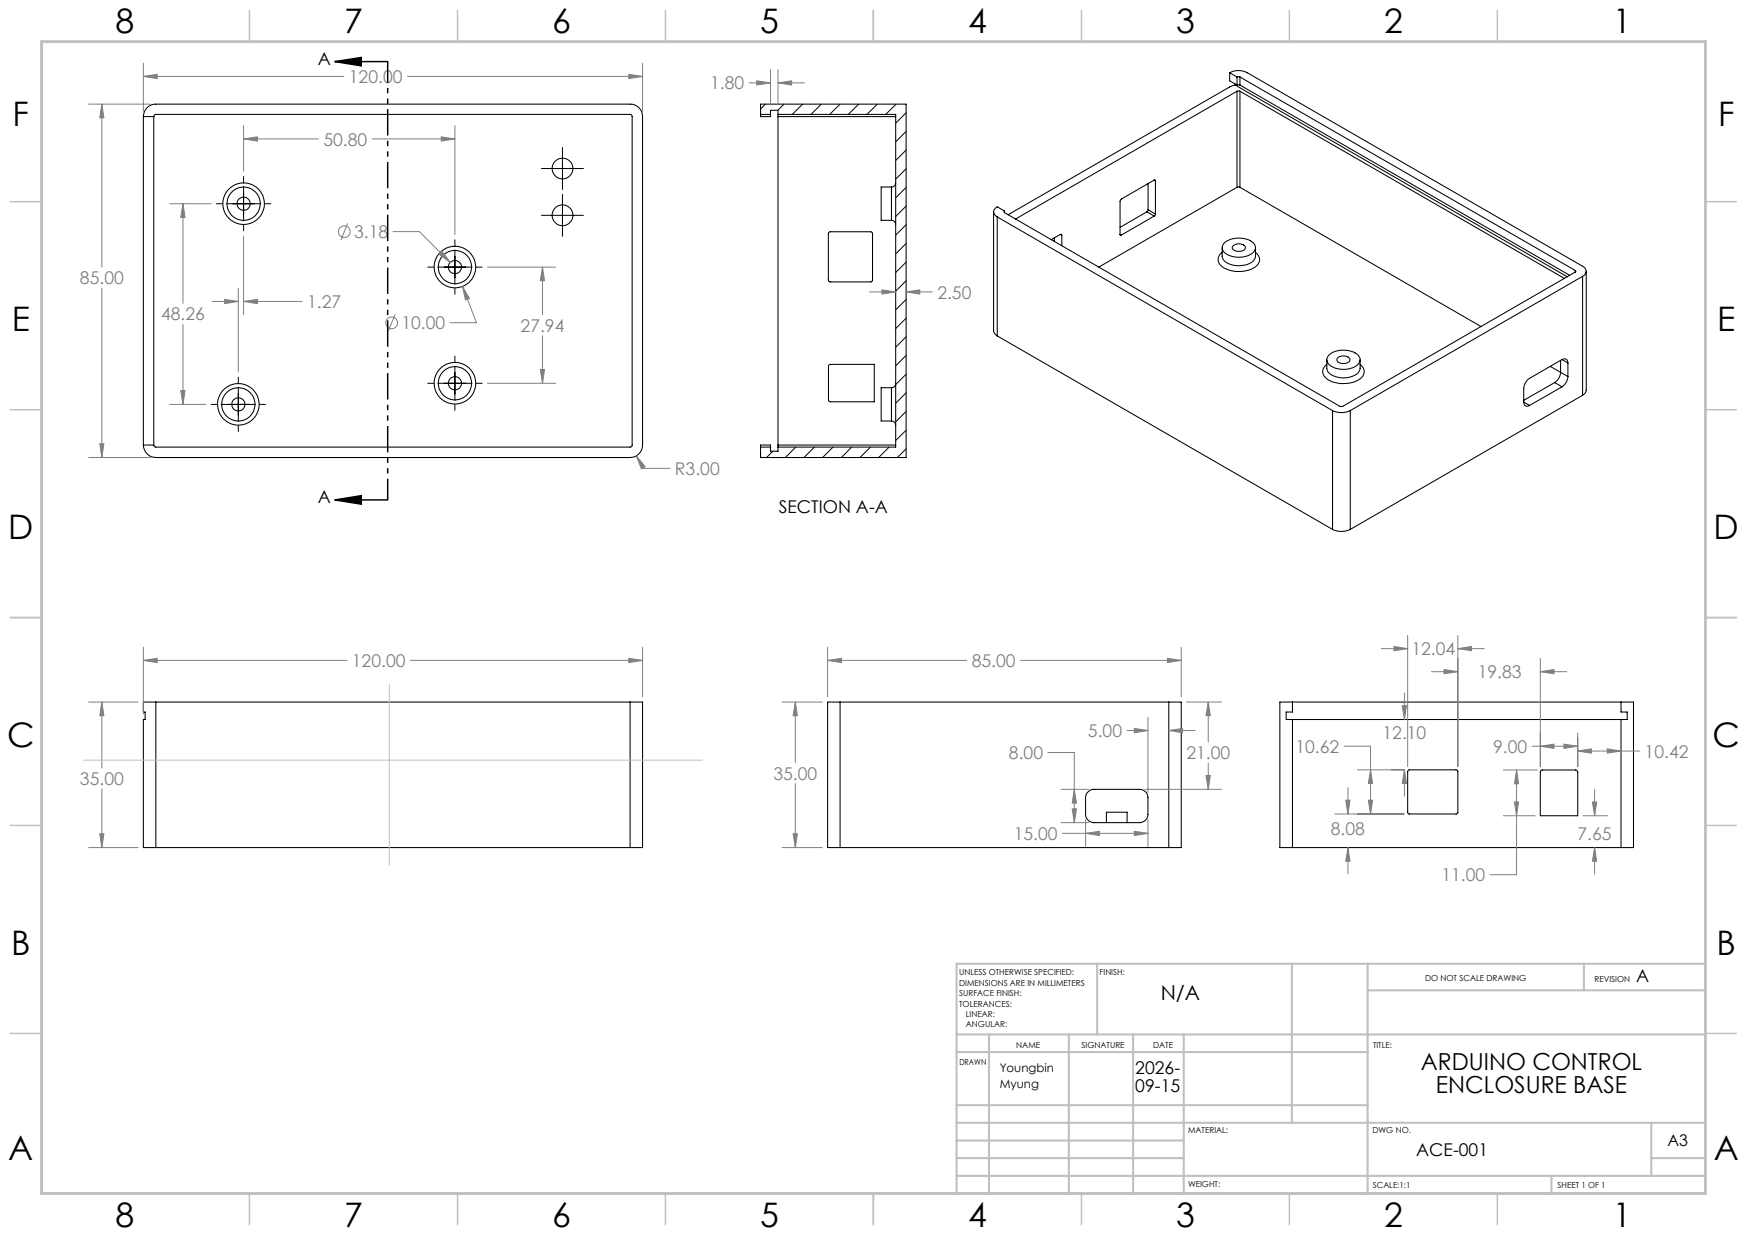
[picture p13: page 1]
SECTION A-A; DO NOT SCALE DRAWING; REVISION; DWG NO.; SCALE:1:1; SHEET 1 OF 1

UNLESS OTHERWISE SPECIFIED:
DIMENSIONS ARE IN MILLIMETERS
SURFACE FINISH:
TOLERANCES:
LINEAR:
ANGULAR:

NAME | SIGNATURE | DATE | TITLE: ARDUINO CONTROL ENCLOSURE BASE

DRAWN | Youngbin Myung | | 2026-09-15

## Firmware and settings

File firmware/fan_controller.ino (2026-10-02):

#include <Wire.h>
#include <LiquidCrystal_I2C.h>

// ============================================================
// Arduino-Controlled 3D Printer Enclosure
//
// Hardware:
// - Arduino Uno R3
// - LM35 temperature sensor
// - 10 kOhm potentiometer
// - N-channel MOSFET controlling two DC fans
// - 16x2 I2C LCD
//
// Control behavior:
// - Potentiometer selects a desired temperature from 25-40 C.
// - Fans remain off when measured temperature is at/below setpoint.
// - Above the setpoint, fan PWM increases proportionally.
// - Fans reach full commanded PWM approximately 10 C above setpoint.
// - PWM output is smoothed to reduce abrupt speed changes.
// ============================================================


// -------------------- LCD --------------------

// Common I2C address for PCF8574-based 16x2 LCD modules.
// If the physical display does not respond, some modules use 0x3F.
LiquidCrystal_I2C lcd(0x27, 16, 2);


// -------------------- Pin assignments --------------------

const int TEMP_PIN = A0;   // LM35 analog output
const int POT_PIN = A1;    // Potentiometer wiper
const int FAN_PWM_PIN = 3; // PWM output to MOSFET gate circuit


// -------------------- Analog settings --------------------

const float ADC_REFERENCE_VOLTAGE = 5.0;
const int ADC_MAX_VALUE = 1023;

const int NUM_SAMPLES = 20;
const int SAMPLE_DELAY_MS = 2;


// -------------------- Temperature settings --------------------

// Adjustable setpoint range controlled by potentiometer.
const float MIN_SETPOINT_C = 25.0;
const float MAX_SETPOINT_C = 40.0;

// LM35 output is approximately 10 mV / degree C
// with approximately 0 V corresponding to 0 C.
const float LM35_VOLTS_PER_C = 0.010;


// -------------------- Fan settings --------------------

// Minimum PWM command used once cooling is requested.
//
// A value greater than zero is useful because many DC fans will
// not reliably turn at extremely small PWM duty cycles.
const int MIN_ACTIVE_PWM = 80;
const int MAX_PWM = 255;

// Fan reaches maximum commanded PWM when temperature is this
// many degrees above the selected setpoint.
const float FULL_SPEED_DELTA_C = 10.0;

// Smoothing factor:
// 0.0 = output never changes
// 1.0 = output immediately reaches target
//
// 0.10 gives gradual changes while remaining responsive.
const float PWM_SMOOTHING_FACTOR = 0.10;

float smoothedPWM = 0.0;


// -------------------- Timing --------------------

const unsigned long UPDATE_INTERVAL_MS = 500;
unsigned long previousUpdateTime = 0;


// ============================================================
// Helper functions
// ============================================================

// Read an analog pin several times and return the average.
//
// Averaging helps reduce small fluctuations in the ADC reading.
float readAverageADC(int pin) {
  long sum = 0;

  for (int i = 0; i < NUM_SAMPLES; i++) {
    sum += analogRead(pin);
    delay(SAMPLE_DELAY_MS);
  }

  return sum / (float)NUM_SAMPLES;
}


// Convert a value from one floating-point range to another.
//
// Arduino's standard map() function operates using integer
// arithmetic, so this function is used when temperatures or
// averaged ADC readings contain decimal values.
float mapFloat(
  float value,
  float inputMin,
  float inputMax,
  float outputMin,
  float outputMax
) {
  return (value - inputMin)
         * (outputMax - outputMin)
         / (inputMax - inputMin)
         + outputMin;
}


// Read the LM35 and return temperature in degrees Celsius.
float readTemperatureC() {
  float adcReading = readAverageADC(TEMP_PIN);

  float voltage =
    adcReading * (ADC_REFERENCE_VOLTAGE / ADC_MAX_VALUE);

  // LM35: approximately 10 mV per degree Celsius.
  return voltage / LM35_VOLTS_PER_C;
}


// Read the potentiometer and convert it into the user's
// desired enclosure temperature.
float readSetpointC() {
  float potReading = readAverageADC(POT_PIN);

  float setpoint = mapFloat(
    potReading,
    0.0,
    ADC_MAX_VALUE,
    MIN_SETPOINT_C,
    MAX_SETPOINT_C
  );

  return constrain(
    setpoint,
    MIN_SETPOINT_C,
    MAX_SETPOINT_C
  );
}


// Calculate the required fan PWM command.
//
// At or below the setpoint:
//     fan target = 0
//
// Immediately above the setpoint:
//     fan target begins at MIN_ACTIVE_PWM
//
// At setpoint + FULL_SPEED_DELTA_C:
//     fan target = 255
//
// Above that:
//     command remains at 255.
int calculateTargetPWM(
  float temperatureC,
  float setpointC
) {
  if (temperatureC <= setpointC) {
    return 0;
  }

  float pwm = mapFloat(
    temperatureC,
    setpointC,
    setpointC + FULL_SPEED_DELTA_C,
    MIN_ACTIVE_PWM,
    MAX_PWM
  );

  pwm = constrain(
    pwm,
    (float)MIN_ACTIVE_PWM,
    (float)MAX_PWM
  );

  return (int)round(pwm);
}


// Update the smoothed PWM value and return the integer command
// that will actually be sent to analogWrite().
int updateFanPWM(int targetPWM) {

  smoothedPWM +=
    (targetPWM - smoothedPWM) * PWM_SMOOTHING_FACTOR;

  // Prevent the floating-point smoother from sitting forever
  // just above zero after the fan has been commanded off.
  if (targetPWM == 0 && smoothedPWM < 1.0) {
    smoothedPWM = 0.0;
  }

  // Likewise, settle exactly on the upper target.
  if (
    targetPWM == MAX_PWM &&
    smoothedPWM > MAX_PWM - 1.0
  ) {
    smoothedPWM = MAX_PWM;
  }

  int pwmOutput = (int)round(smoothedPWM);

  return constrain(
    pwmOutput,
    0,
    MAX_PWM
  );
}


// Update the 16x2 LCD.
//
// Clearing each row before writing prevents leftover characters
// when a value changes from a longer number to a shorter one.
void updateLCD(
  float temperatureC,
  float setpointC,
  int fanPercent,
  bool fanOn
) {

  // Clear first row.
  lcd.setCursor(0, 0);
  lcd.print("                ");

  // Display measured temperature.
  lcd.setCursor(0, 0);
  lcd.print("Temp:");
  lcd.print(temperatureC, 1);
  lcd.print((char)223); // LCD degree symbol
  lcd.print("C");


  // Clear second row.
  lcd.setCursor(0, 1);
  lcd.print("                ");

  // Display desired temperature and commanded fan percentage.
  lcd.setCursor(0, 1);
  lcd.print("Des:");
  lcd.print(setpointC, 1);

  lcd.setCursor(9, 1);
  lcd.print(fanPercent);
  lcd.print("%");

  // Status indicator in final LCD column.
  lcd.setCursor(15, 1);

  if (fanOn) {
    lcd.print(">");
  } else {
    lcd.print(" ");
  }
}


// Send diagnostic information to the Serial Monitor.
void printSerialDiagnostics(
  float temperatureC,
  float setpointC,
  int targetPWM,
  int actualPWM
) {
  int fanPercent =
    (int)round((actualPWM / 255.0) * 100.0);

  Serial.print("Temperature: ");
  Serial.print(temperatureC, 1);
  Serial.print(" C");

  Serial.print(" | Setpoint: ");
  Serial.print(setpointC, 1);
  Serial.print(" C");

  Serial.print(" | Target PWM: ");
  Serial.print(targetPWM);

  Serial.print(" | Output PWM: ");
  Serial.print(actualPWM);

  Serial.print(" | Fan command: ");
  Serial.print(fanPercent);
  Serial.print("%");

  if (actualPWM > 0) {
    Serial.println(" | ON");
  } else {
    Serial.println(" | OFF");
  }
}


// ============================================================
// Arduino setup
// ============================================================

void setup() {

  pinMode(FAN_PWM_PIN, OUTPUT);

  // Make sure the fans are initially commanded off.
  analogWrite(FAN_PWM_PIN, 0);

  // Start LCD.
  lcd.init();
  lcd.backlight();

  // Startup message.
  lcd.setCursor(0, 0);
  lcd.print("Enclosure Fan");

  lcd.setCursor(0, 1);
  lcd.print("Controller");

  // Start Serial Monitor.
  Serial.begin(9600);
  Serial.println();
  Serial.println(
    "Arduino 3D Printer Enclosure Controller"
  );
  Serial.println(
    "System initialized."
  );

  delay(1500);

  lcd.clear();
}


// ============================================================
// Main program loop
// ============================================================

void loop() {

  unsigned long currentTime = millis();

  // Update approximately every 500 ms.
  if (
    currentTime - previousUpdateTime
    < UPDATE_INTERVAL_MS
  ) {
    return;
  }

  previousUpdateTime = currentTime;


  // 1. Measure enclosure temperature using the LM35.
  float temperatureC = readTemperatureC();


  // 2. Read the user's desired temperature from the
  //    potentiometer.
  float setpointC = readSetpointC();


  // 3. Determine the desired fan PWM command.
  int targetPWM =
    calculateTargetPWM(
      temperatureC,
      setpointC
    );


  // 4. Smooth the fan command.
  int fanPWM =
    updateFanPWM(targetPWM);


  // 5. Send PWM to the MOSFET.
  //
  // The Arduino is NOT powering the fans directly.
  // This PWM signal drives the MOSFET gate circuit,
  // which switches the fan current.
  analogWrite(
    FAN_PWM_PIN,
    fanPWM
  );


  // 6. Convert commanded PWM to percentage for display.
  //
  // This is commanded PWM percentage, NOT measured fan RPM.
  int fanPercent =
    (int)round(
      (fanPWM / 255.0) * 100.0
    );

  bool fanOn = fanPWM > 0;


  // 7. Update LCD.
  updateLCD(
    temperatureC,
    setpointC,
    fanPercent,
    fanOn
  );


  // 8. Output diagnostic information.
  printSerialDiagnostics(
    temperatureC,
    setpointC,
    targetPWM,
    fanPWM
  );
}

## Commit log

2026-08-26 Initial commit: Arduino 3D printer enclosure documentation
2026-08-26 Add prototype photo and demo video
2026-08-26 Refactor fan controller code for clarity and maintainability
    Refactor fan controller code for clarity and maintainability. Introduce constants for pin assignments and settings, improve comments, and streamline logic for temperature and fan control.
2026-08-26 Revise README for clarity and detail enhancement
    Updated the README to enhance clarity and detail about the Arduino-controlled temperature regulation system for a 3D printer enclosure, including contributions, system architecture, and limitations.
2026-08-26 Revise testing and limitations documentation
    Expanded documentation on testing, limitations, and future improvements for the prototype. Clarified evidence and functional testing details.
2026-08-26 Revise media README for Arduino 3D printer enclosure
    Updated README to reflect project details and functionality of the Arduino-controlled 3D printer enclosure, including system architecture, hardware components, and operational notes.
2026-08-26 Replace local image links with Google Drive links
    Updated image links for the prototype and demo sections.
2026-08-26 Replace prototype image link in README
    Updated image link for the Arduino-controlled 3D printer enclosure.
2026-08-26 Change prototype image format from JPG to HEIC
    Updated image format for prototype overview in README.
2026-08-26 Add prototype_demo.MOV file
2026-08-26 Change prototype image in README
    Updated the prototype image in the README file.
2026-08-26 Replace local prototype image with hosted link
    Updated the prototype image link to a hosted version.
2026-10-02 Improve mechanical design documentation and CAD portfolio presentation
    [ACE-001_Arduino_Control_Enclosure_Base.SLDDRW, ACE-002_Sliding_Lid.SLDDRW, ACE-003_Arduino_Control_Enclosure_Assembly.SLDDRW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]
